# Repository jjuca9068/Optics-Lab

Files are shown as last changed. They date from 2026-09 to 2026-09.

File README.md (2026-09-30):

# Table of Contents
* [1. Lab Stage Mounts (3D CAD Design)](#1-optical-fiber-heating-enclosure-3d-cad-design)
* [2. Integrated Lab Control & Vision System GUI](#2-integrated-lab-control--vision-system-gui)
* [3. Hydrogen Flame Draft Protection Enclosure](#3-hydrogen-flame-draft-protection-enclosure)
* [4. Project Presentations & Documentation](#4-project-presentations--documentation)
---

# 1. Quantum Optics Lab Stage Mounts
Personal portfolio and technical projects for the MTSU Quantum Optics Lab, featuring custom CAD hardware, mechanical frame layouts, and an AI-assisted instrument control system.

### 1.1 Project Task & Engineering Challenge
* **Objective:** Securely mount specialized fiber holders onto translational stages to draw optical fiber under controlled tension over a hydrogen flame.
* **Constraints:** Commercial stage hardware lacked the proper clearance, vertical offset, and stability required for precise repeatable results.
* **Goal:** Design, iterate, and deploy a custom, high-rigidity stage mount to optimize precision and repeatability.

---

### 1.2 Design Logic & Prototyping Approach
* **Modular Two-Part System:** Split the mount into a **Base Plate** (interfaces directly with the stage) and a **Top Bracket** (clamps the fiber fixture) for fast alignment adjustments and component swapping.
* **Universal Dual-Hole Pattern:** Integrated symmetric mounting holes into the base plate design. This allows a single printed part to be deployed interchangeably on either the left or right side of the stage setup, eliminating the need to design and manage separate left- and right-handed models.
* **Prototyping Strategy:** Utilized 3D-printed PETG/PLA for rapid dimensional validation and clearance testing before final deployment.
* **Thermal Considerations:** Designed clearance offsets relative to the flame source to prevent localized heating or material sagging during active fiber drawing runs.

---

### 1.3 Iteration History & Development

#### Phase 1: Early Prototypes & Initial Fit Check
Initial spatial checks to test stage mounting hole spacing and overall base plate geometry.

| Base Plate (V1) | Stage Fit Check Assembly |
| :---: | :---: |
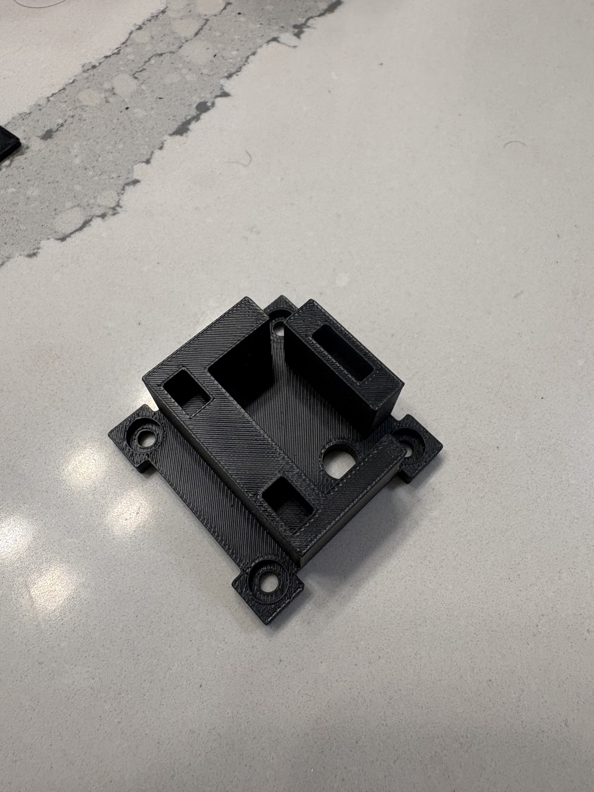
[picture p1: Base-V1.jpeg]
Base V1
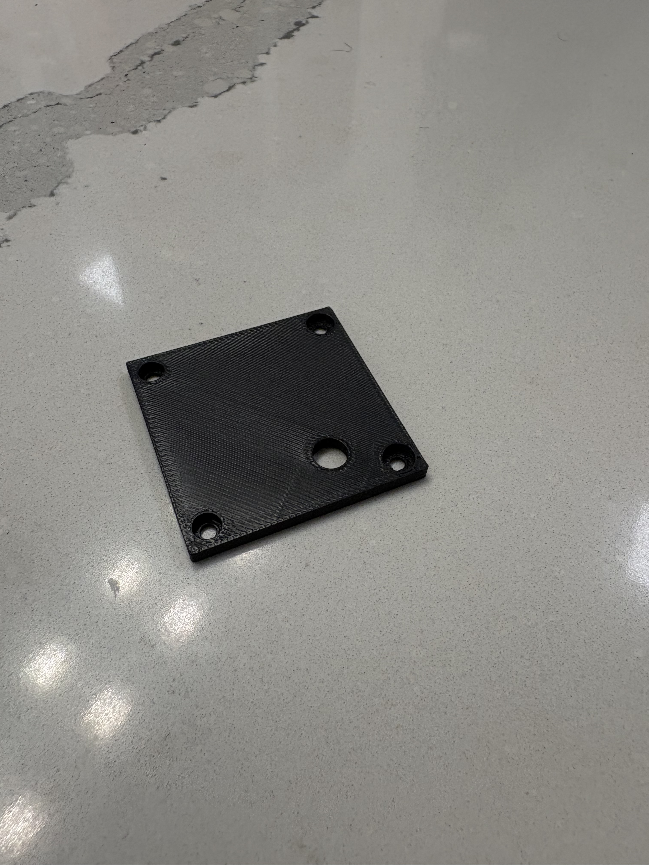
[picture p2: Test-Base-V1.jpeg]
Test Assembly
|  |  |
| *Initial base mounting plate* | *Assembled fit-check on stage* |

---

#### Phase 2: Top Bracket & Binding Clearance Analysis
Evaluating upper bracket geometry and identifying translation binding issues.

| Top Bracket (V1) | Failed Fit Check (Side View) |
| :---: | :---: |
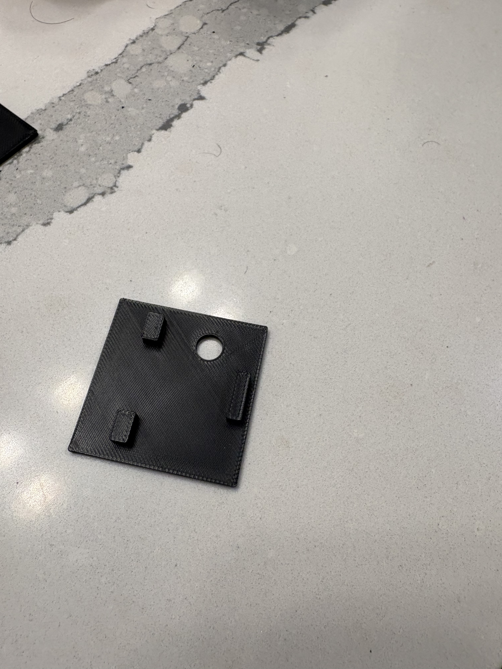
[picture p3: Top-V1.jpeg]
Top V1
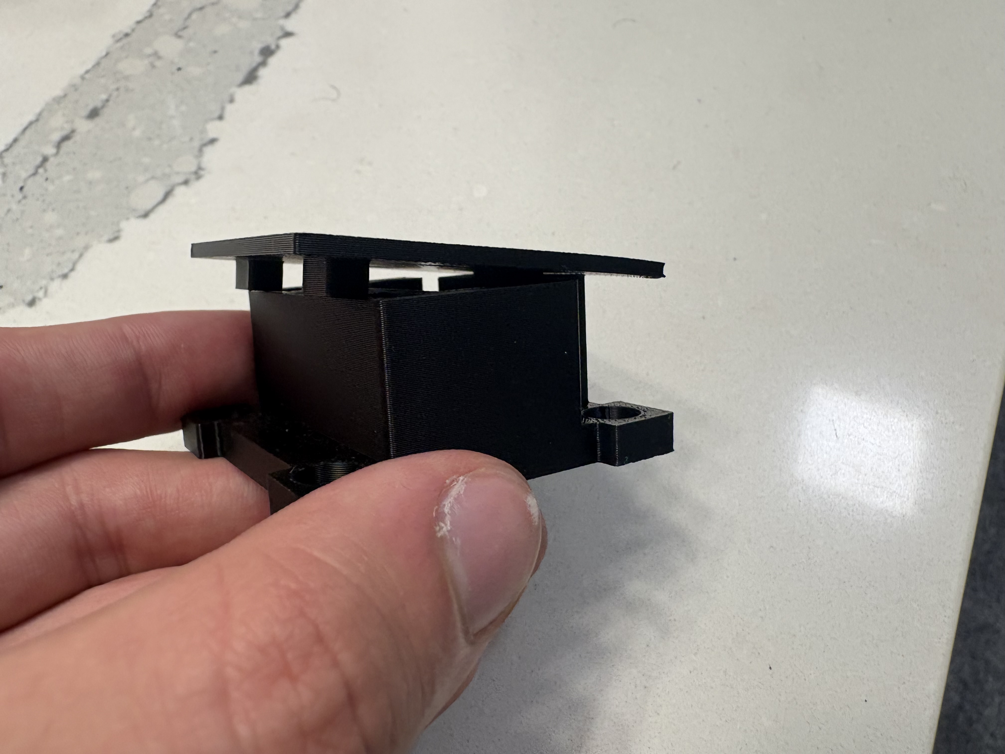
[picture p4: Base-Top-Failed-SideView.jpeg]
Failed Side View
|  |  |
| *First top bracket geometry* | *Side view clearance breakdown* |

* **Key Finding:** Initial V1 geometry did not line up. Adjustments were made to side offsets and hole counterbores for subsequent revisions.

---

#### Phase 3: Refined Base Plate Geometry & Alignment Fit
Upgraded base plate design featuring reinforced side walls, corrected stage hole tolerances, and physical fit verification.

| Base Plate (V2) | Alignment Verification |
| :---: | :---: |
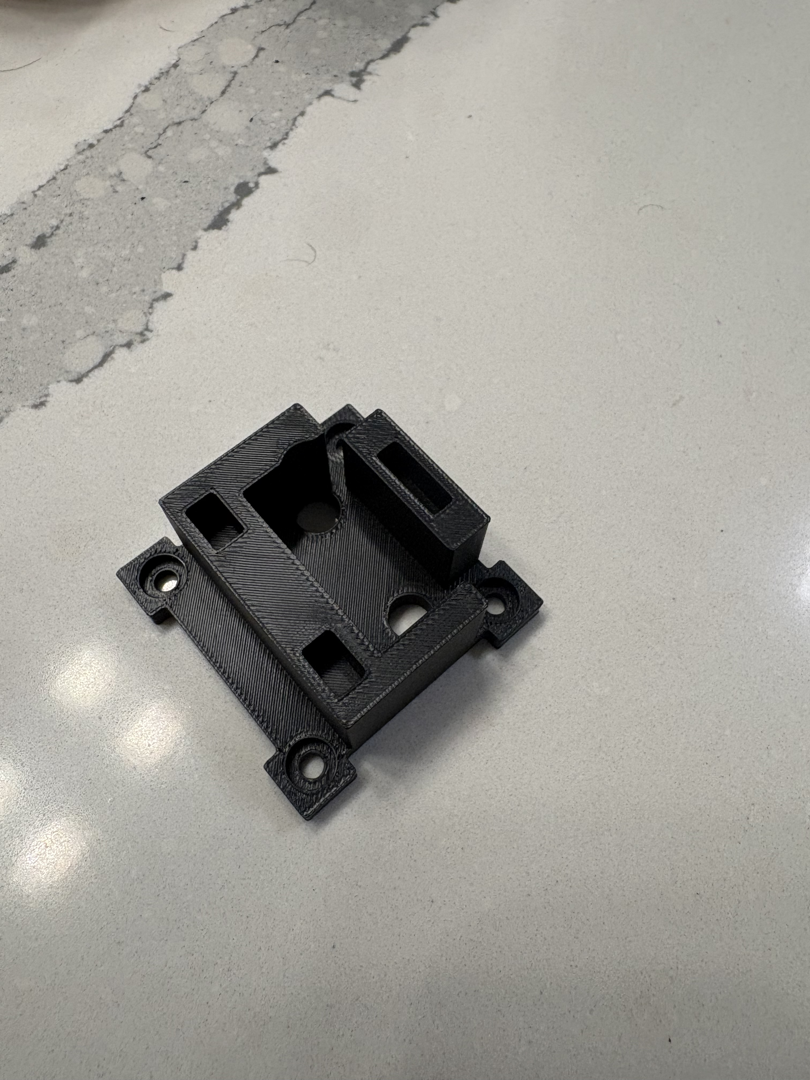
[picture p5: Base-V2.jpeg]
Base V2
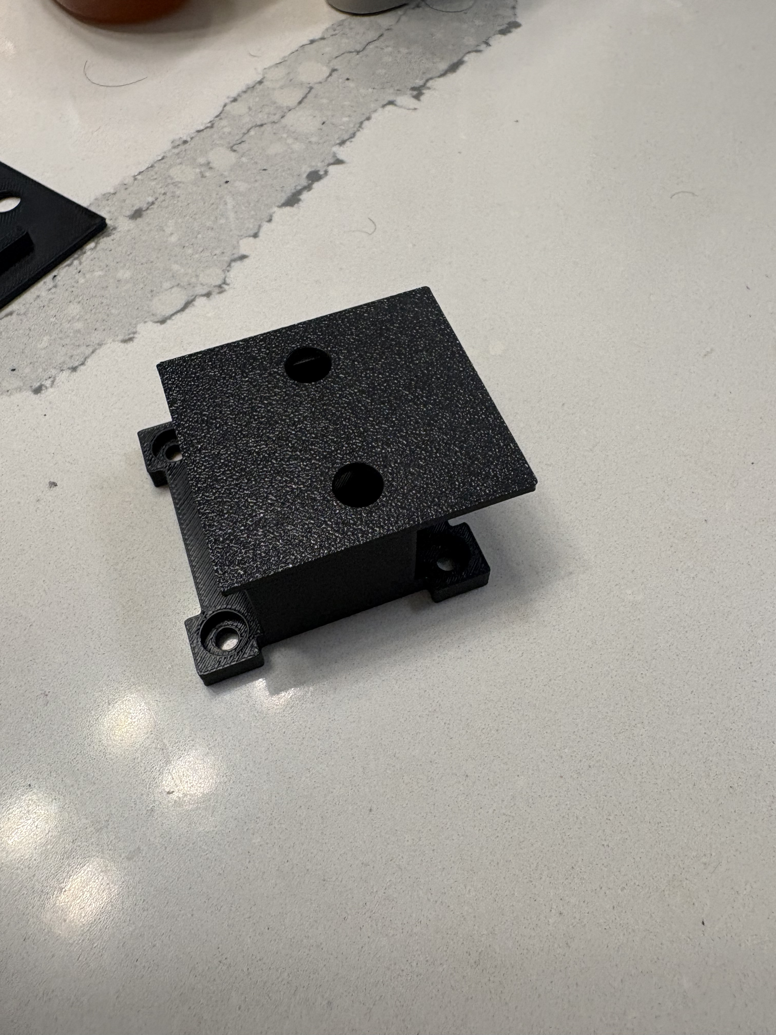
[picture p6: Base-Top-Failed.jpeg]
Failed Alignment
|  |  |
| *Reinforced base plate V2* | *Alignment verification and clearance test* |

---

#### Phase 4: Final Production Setup
Final assembly integrated and active in the laboratory fiber tapering rig.

| Final Deployment | Overhead View | Mount Interface Detail |
| :---: | :---: | :---: |
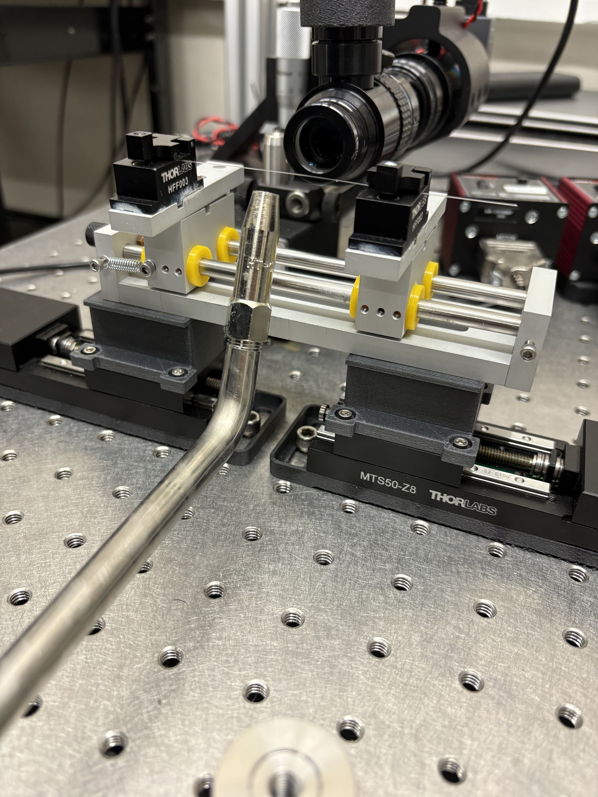
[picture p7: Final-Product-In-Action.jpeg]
Final Assembly
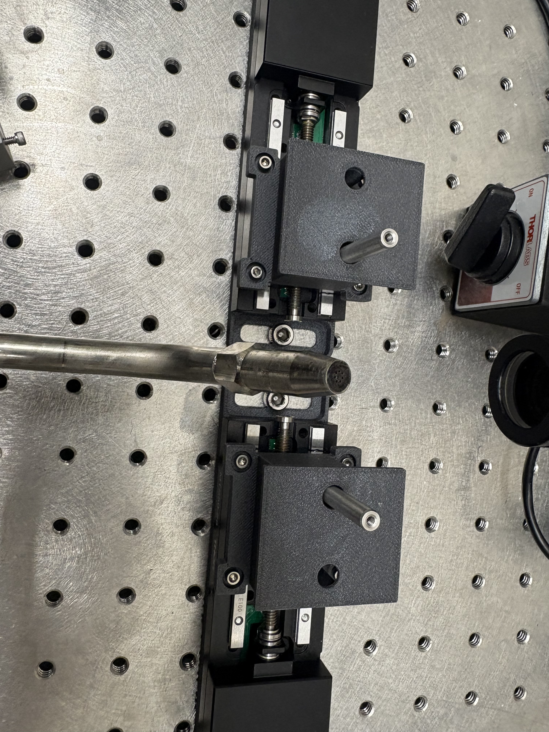
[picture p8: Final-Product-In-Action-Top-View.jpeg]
Top View
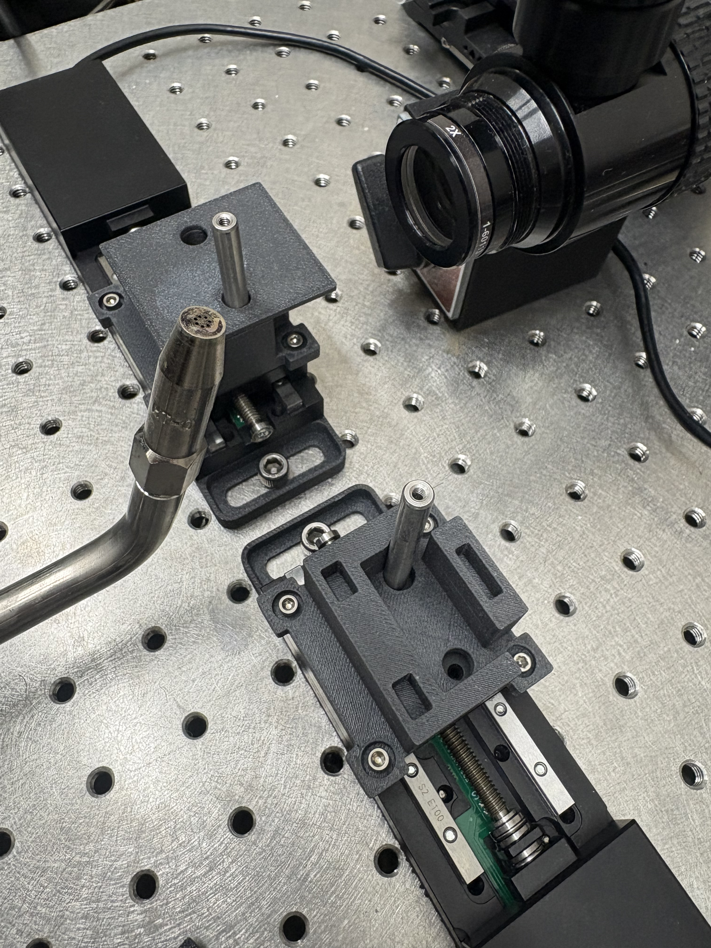
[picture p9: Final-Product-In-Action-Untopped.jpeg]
Untopped
|  |  |  |
| *In operation over hydrogen flame* | *Overhead optical alignment check* | *Stage mounting interface* |

---

### 1.4 3D Printable Models (STL)

Click any link below to view or rotate the 3D models directly on GitHub:

* **[Final Design](Final_Design.stl)**
* **[Full Base V2](Full_Base_V2.stl)**
* **[Top V2](Top_V2.stl)**
* **[Top V1](Top_V1.stl)**
* **[Full Base V1](Full_Base_V1.stl)**
* **[Base V1](Base_v1.stl)**
* **[Prototype 2](Prototype_number_2.stl)**
* **[Prototype 1](Prototype_number_1.stl)**

---

### 1.5 Summary & Key Results
* **Alignment & Versatility:** Successfully eliminated stage binding with a dual-hole universal base plate that mounts on either side of the setup.
* **Rigidity:** Modular clamp system holds fiber under tension without mechanical drift.
* **Cost & Time:** Iterated through spatial fit checks via 3D printing in hours, bypassing expensive trial-and-error machining.

### 2.1 Hardware Architecture & System Goals

* **Primary Objective:** Unify separate hardware peripherals (motor controllers and high-resolution camera feed) into one cohesive, browser-accessible dashboard.
* **Core Functionality:** Enable real-time motor stage translation, synchronized sequence routines, live video feed observation, image capture, and calibrated spatial measurements in micrometers ($\mu\text{m}$).

| System Goals | Integrated Hardware Peripherals |
| :--- | :--- |
| • **Simplified Motor Control:** Centralized axis position monitoring, homing, and safety stops. | • **2x Thorlabs Motor Controllers** (KDC101 Servo Controllers) |
| • **Unified Interface:** Integrated live camera streaming alongside dual-axis translation controls. | • **2x Thorlabs Translation Stages** |
| • **Preset Camera Control:** Adjustable exposure, gain, auto-scaling, and resolution controls. | • **1x Pixelink Industrial Camera** |
| • **In-Situ Measurement:** Direct pixel-to-micrometer dimensional measurement overlay. | • **1x Optical Microscope Assembly** |

---

### 2.2 System Architecture & Logic Map

The application follows a full-stack architecture with an asynchronous HTTP API layer linking the client dashboard to hardware-driver Python scripts.

| System Logic & Software Flow |
| :---: |
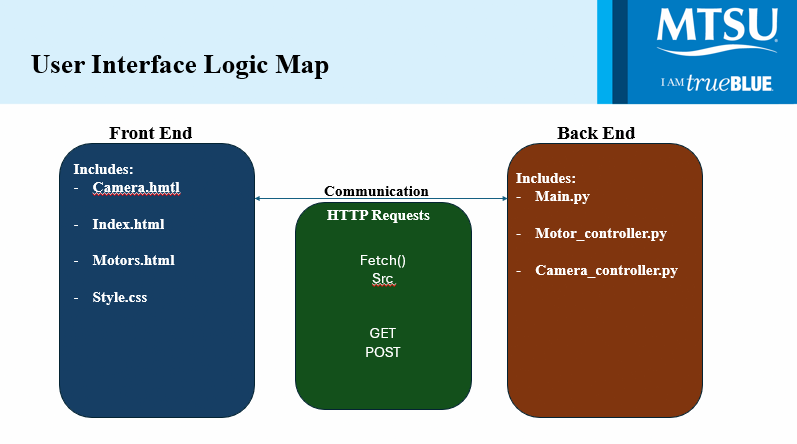
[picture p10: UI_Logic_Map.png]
User Interface Logic Map
|  |
| *Frontend-to-backend communication architecture via HTTP GET/POST requests* |

#### Technical Stack Breakdown:
* **Front End:** HTML5, CSS3, JavaScript (Fetch API for asynchronous `GET`/`POST` requests, responsive canvas overlays for measurement calculations).
* **Back End:** Python (RESTful API hosting via `main.py`), controlling physical devices through submodules (`motor_controller.py` and `camera_controller.py`).
* **Communication Protocols:** JSON payload response handling for real-time motor telemetry (positioning, idle status) and live video streaming.

---

### 2.3 System Layout & Hardware Deployment

The entire system runs on a dedicated laboratory laptop, providing direct USB interface lines to all optomechanical components mounted on the optical table.

| Presentation View | Physical Laboratory Setup |
| :---: | :---: |
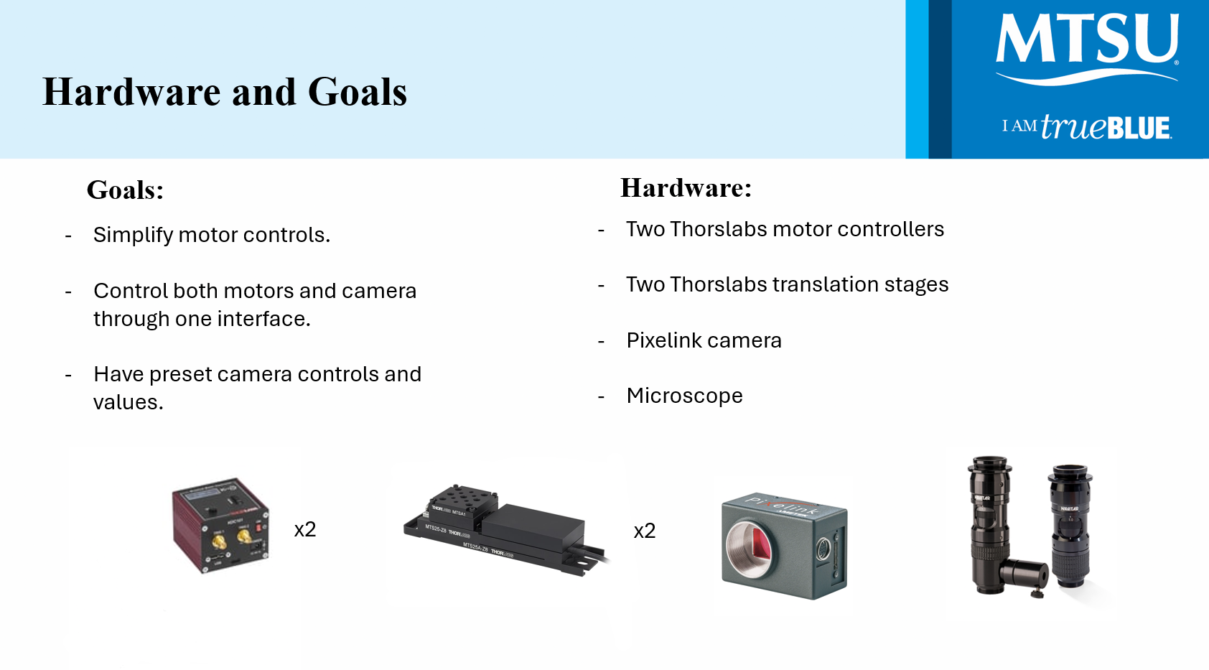
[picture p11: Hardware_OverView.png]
Hardware Overview
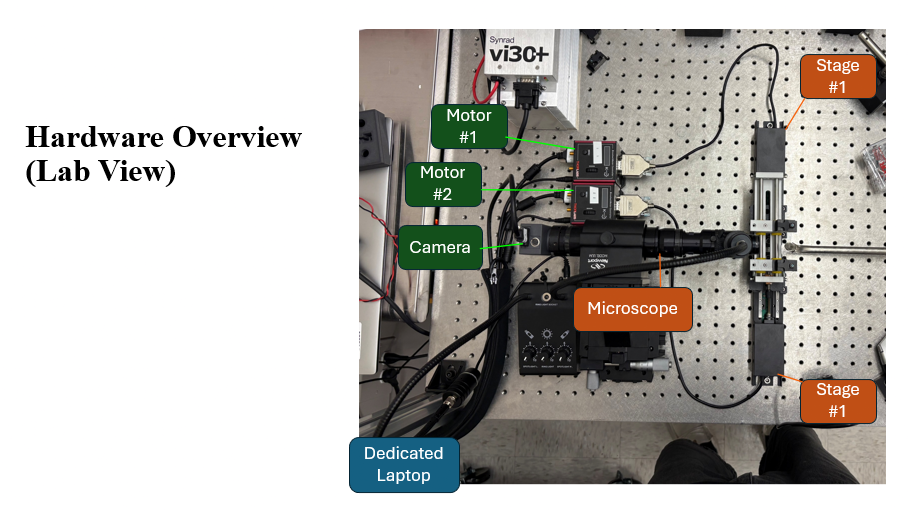
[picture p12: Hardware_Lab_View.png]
Lab Hardware Setup
|  |  |

---

### 2.4 User Interface & Operational Control

#### 1. Main Control Dashboard (`index.html`)
Consolidates motor operations and vision streaming into a single view for active experimentation.

| Dashboard Overview | Key Dashboard Features |
| :---: | :--- |
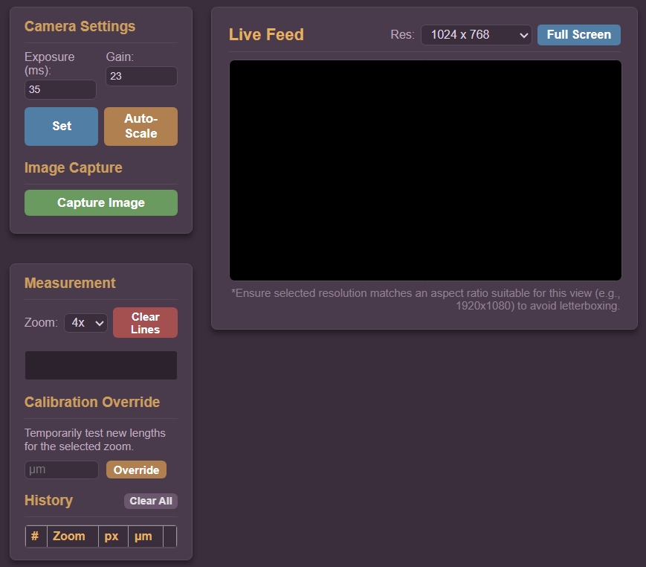
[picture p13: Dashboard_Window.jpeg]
Main Dashboard
|  | • **Dual Motor Monitoring:** Live position readout ($mm$) and status tracking (Idle / Active).<br>• **Independent Axis Actions:** Homing, pausing, resuming, and stopping per motor.<br>• **Global Safety Controls:** One-click `Pause Both`, `Resume Both`, and emergency `Stop Both`.<br>• **Automated Sequences:** Dropdown selector to execute synchronized movement routines.<br>• **Quick Capture:** Instant single-frame optical capture directly from the main view. |

---

#### 2. Detailed Motor Control View (`motors.html`)
Dedicated view for granular dual-axis stage configuration, step control, and sequence selection.

| Motor Control Interface | Key Capabilities |
| :---: | :--- |
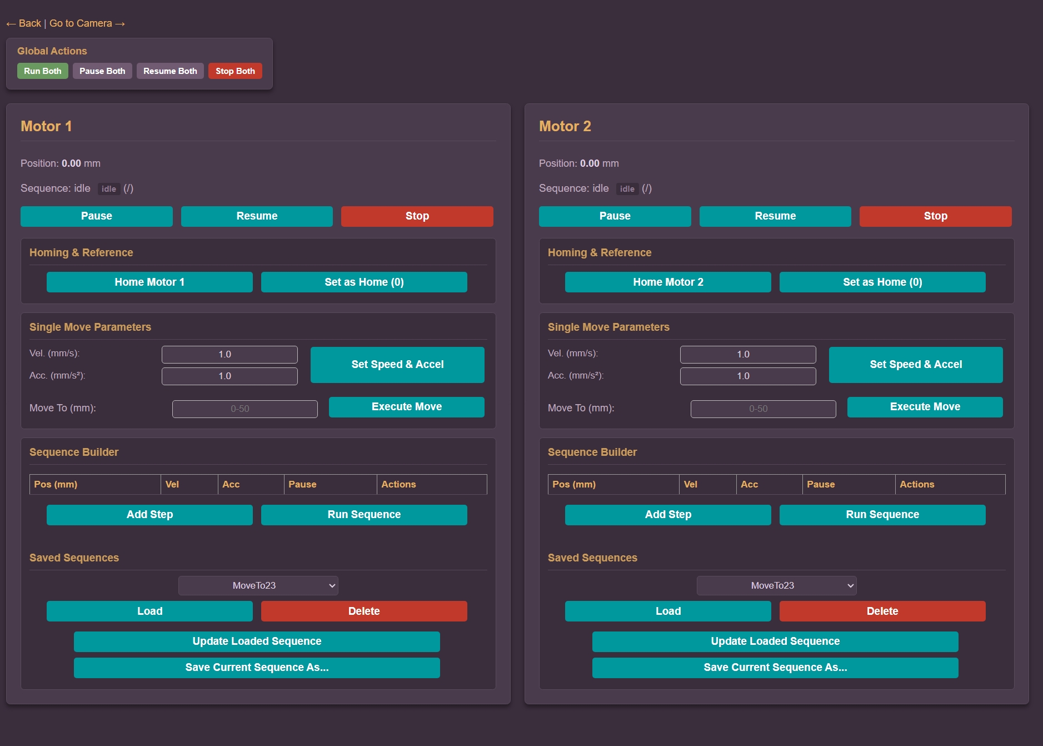
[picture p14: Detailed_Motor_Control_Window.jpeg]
Detailed Motor Control
|  | • **Axis Specific Readouts:** Individual telemetry windows for Stage 1 and Stage 2.<br>• **Manual & Step Moves:** Direct step-size configuration for precision alignment.<br>• **Independent Axis Safety:** Individual Home, Pause, Resume, and Stop toggles per motor driver.<br>• **Routine Automation:** Direct access to automated drawing and translation scripts. |

---

#### 3. Specialized Camera & Dimensional Measurement View (`camera.html`)
Dedicated view for fine alignment, sensor parameter tuning, and in-situ micro-scale measurement.

| Camera & Measurement Suite | Features & Capabilities |
| :---: | :--- |
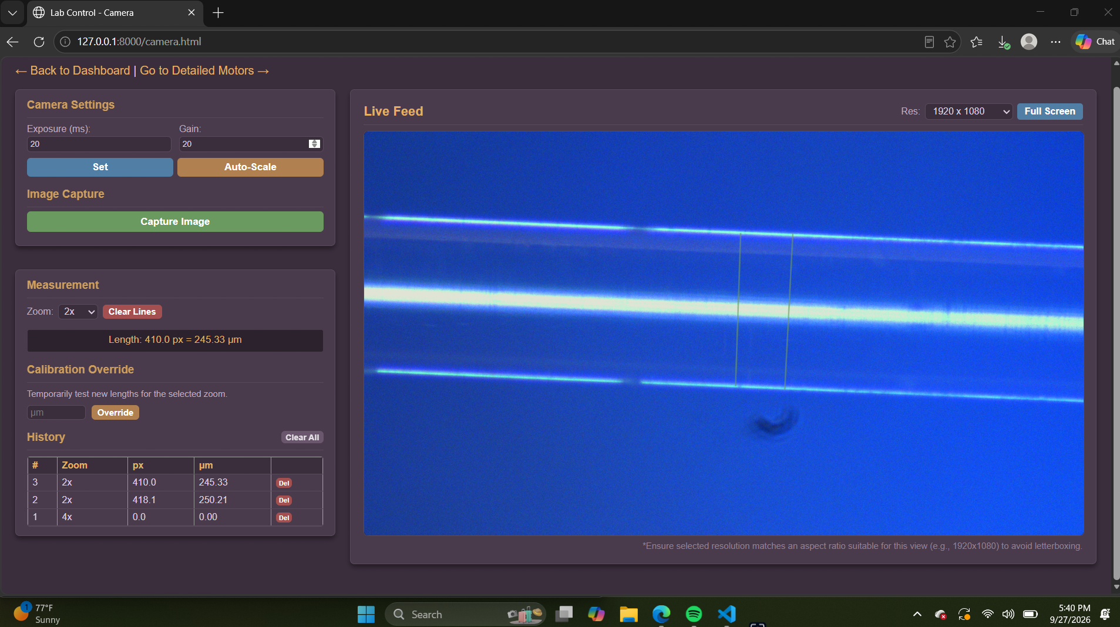
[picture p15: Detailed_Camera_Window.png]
Camera Controls
|  | • **Camera Parameter Tuning:** Manual entry for Exposure ($ms$) and Gain, alongside one-click Auto-Scale.<br>• **Resolution Control:** Selectable aspect ratios up to $5472 \times 3648$.<br>• **Micrometer Calibration Overlay:** Interactive line-drawing tool converts pixel distance ($px$) directly to micro-scale length ($\mu\text{m}$) based on selected microscope zoom magnification ($1\text{x}, 2\text{x}, 4\text{x}$).<br>• **Measurement Log & Calibration Override:** Real-time history table keeping track of measured fiber dimensions with quick deletion and manual calibration test overrides. |

---

### 2.5 Software Repository & Source Files

Click any file below to view the source code directly in this repository:

#### **Back End (Python Server & Controllers)**
* 🐍 **[main.py](./main.py)** – Server entry point, API route management (`GET`/`POST`), and initialization routines.
* 🐍 **[motor_controller.py](./motor_controller.py)** – Driver interface translating API commands into Thorlabs motor translation movement.
* 🐍 **[camera_controller.py](./camera_controller.py)** – Pixelink camera SDK wrapper for frame capture, exposure adjustments, and video feed serving.

#### **Front End (User Interface)**
* 📄 **[index.html](./index.html)** – Main laboratory dashboard layout.
* 📄 **[camera.html](./camera.html)** – Dedicated live video feed, camera settings, and line-measurement interface.
* 📄 **[motors.html](./motors.html)** – Detailed standalone motor stage configuration page.
* 🎨 **[style.css](./style.css)** – UI styling, dark mode theme, and responsive panel layouts.

---

### 2.6 Summary & Key Accomplishments

* **Integrated Workflow:** Replaced separate, single-purpose vendor software utilities with a lightweight, browser-based control hub.
* **In-Situ Metrology:** Added pixel-calibrated measurement overlays, allowing researchers to measure fiber tapers directly inside the live camera feed without exporting images to external software.
* **Synchronized Automation:** Enabled multi-axis automated movement sequences managed through backend Python routines for repeatable fiber-drawing procedures.

# 3. Hydrogen Flame Draft Protection Enclosure

An environmental isolation frame engineered for the MTSU Quantum Optics Lab to shield sensitive hydrogen micro-flames from ambient laboratory air currents during optical fiber tapering operations.

---

### 3.1 Problem Statement & Solution Overview

* **Problem:** Ambient HVAC airflow and air currents inside the laboratory caused temperature fluctuations and instability in the hydrogen micro-flame, leading to uneven optical fiber tapers.
* **Solution:** Built a rigid 4040 aluminum extrusion frame utilizing heavy-duty corner bracket connectors, sliding T-slot hooks, and flame-retardant protective curtains to isolate the flame zone without interfering with optomechanical stage access.

| Project Focus | Structural Features |
| :--- | :--- |
| • **Flame Stabilization:** Eliminates micro-drafts around the hydrogen burner nozzle. | • **Heavy-Duty Framing:** Industrial-grade 4040 aluminum extrusion rails. |
| • **Unrestricted Lab Access:** Smooth sliding curtain suspension along extrusion slots. | • **Modular Assembly:** Secured via M8 T-slot nuts and corner profile connectors. |

---

### 3.2 Structural Frame, Layout & Assembly Views

| Initial Concept Sketch | Assembled Frame (Top View) | Corner Connector Detail |
| :---: | :---: | :---: |
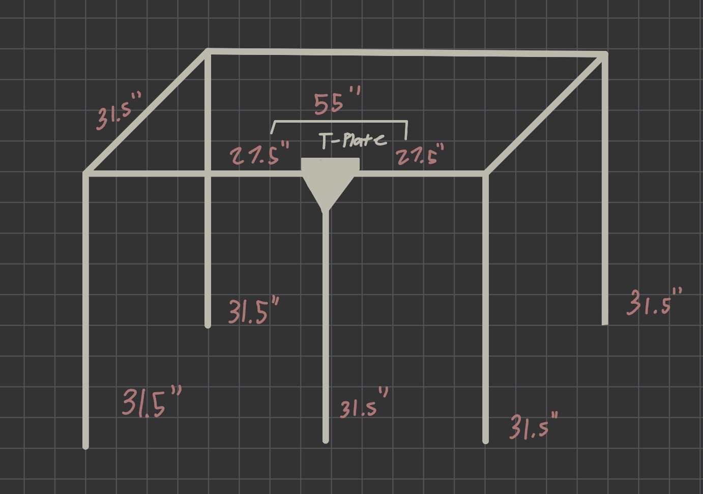
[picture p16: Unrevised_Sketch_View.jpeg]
Initial Concept Sketch
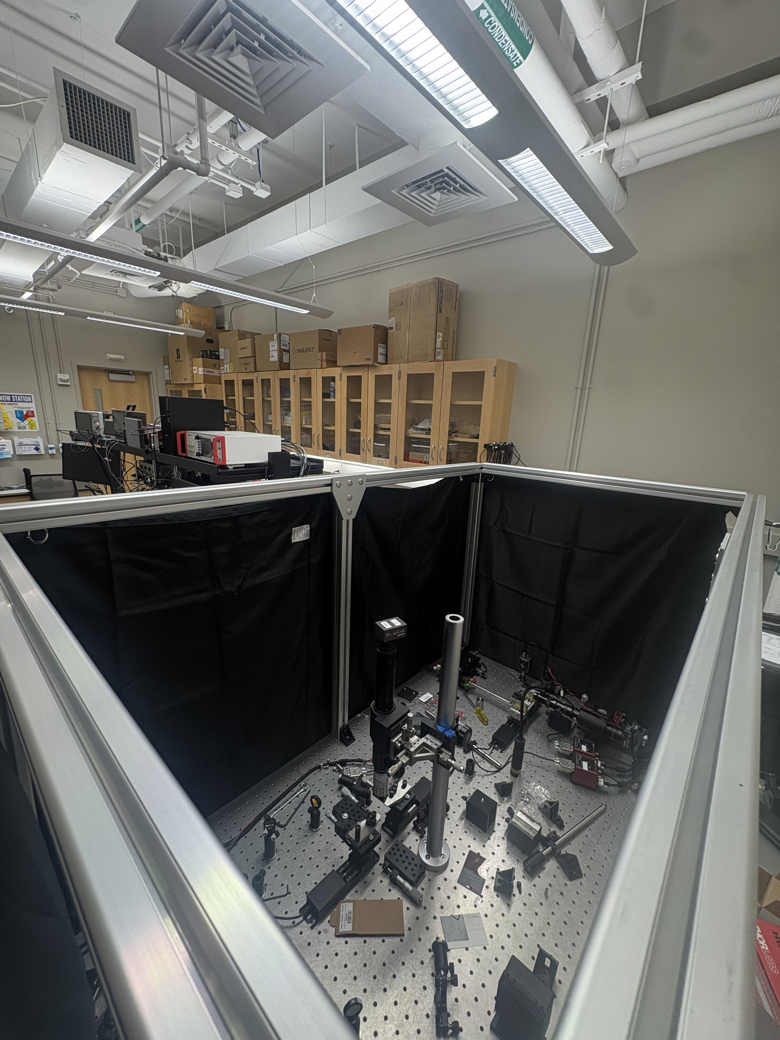
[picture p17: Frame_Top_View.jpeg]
Frame Top View
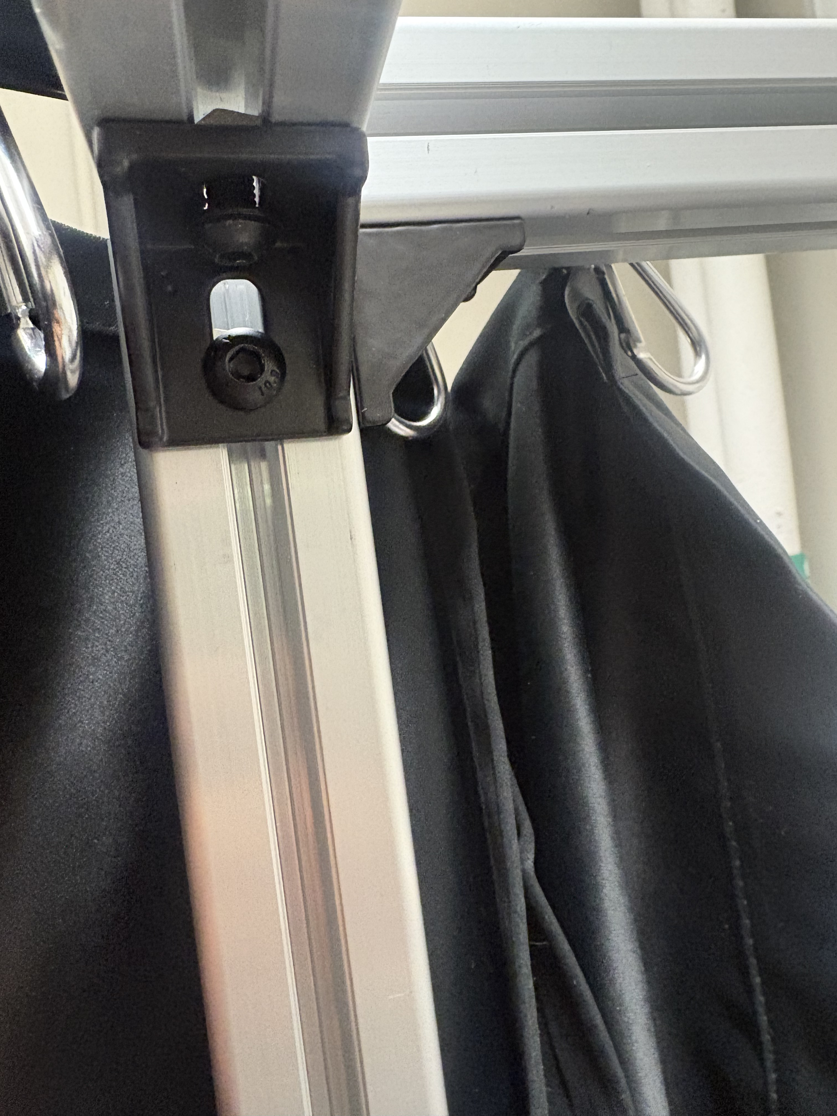
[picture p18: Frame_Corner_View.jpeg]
Corner Joint Detail
|  |  |  |
| *Initial structural layout and dimensioning sketch* | *Top-down perspective of assembled aluminum frame* | *Close-up of 4040 aluminum corner brackets holding frame rails* |

#### Bill of Materials & Hardware Specifications

| Component / Hardware Item | Quantity | Material / Description | Function |
| :--- | :---: | :--- | :--- |
| **4040 Aluminum Extrusion Rails (800mm)** | 6 Rails | Silver Anodized Linear Rail ($800\text{mm}$) | Primary vertical and upper structural framing rails |
| **4040 Aluminum Extrusion Rails (700mm)** | 6 Rails | European Standard Silver Rail ($700\text{mm}$ / 27.5") | Base and cross-member support framing rails |
| **3540 Corner Bracket Connectors** | 14 Units | Black Anodized Corner Profile Connectors | Rigid $90^\circ$ right-angle joint connectors securing rails |
| **Extrusion Sliding Hooks** | 12 Pack | Black 3030/4040 Extrusion T-Slot Hooks | Slide-in rail hooks supporting protective curtains |
| **T-Slot Fasteners & Hex Bolts** | 1 Set | M8 T-Slot Sliding Nuts & Hex Screws | Hardware locking corner brackets into rail grooves |
| **Draft Protection Curtains** | 4 Panels | Flame-Retardant Anti-Draft Vinyl | Hanging barrier blocking ambient HVAC air currents |

---

### 3.3 Summary & Impact

* **Enhanced Flame Stability:** Successfully isolated the hydrogen flame zone from ambient lab drafts, stabilizing thermal delivery during fiber heating.
* **Repeatable Fiber Tapering:** Reduced geometrical variations in drawn optical fibers caused by flicker or flame drift.
* **Modular Construction:** Designed with industrial T-slot profiles allowing quick repositioning or height adjustments on the optical bench.

* ---

# 4. Project Presentations & Slide Decks

Detailed PowerPoint slide presentations covering system design, laboratory architecture, and research methodology for the project components.

| Presentation Slide Deck | File Format | Description & Topic Focus | Direct Link |
| :--- | :---: | :--- | :---: |
| **Web GUI & Instrument Control** | `.pptx` | Overview of the web-based instrument control system, motor stage API, and live camera measurement suite. | 📊 **[`web-GUI-presentation.pptx`](./web-GUI-presentation.pptx)** |
| **Tapered Optical Fiber & WGM** | `.pptx` | Slide deck detailing Tapered Optical Fiber (TOF) fabrication and Whispering Gallery Mode (WGM) optical resonance research. | 📊 **[`TOFxWGM presentation.pptx`](./TOFxWGM%20presentation.pptx)** |

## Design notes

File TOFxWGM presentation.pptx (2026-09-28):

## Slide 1

Tapered Optical Fiber and Whispering-Gallery Mode Resonators

High-Sensitivity Optical Sensing

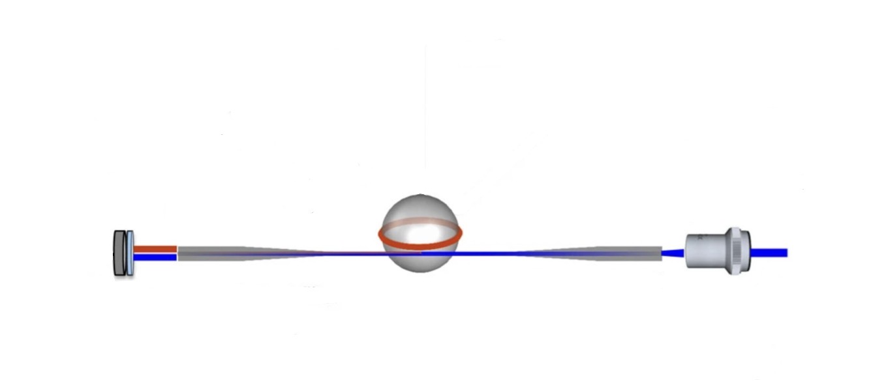
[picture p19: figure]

Jacob Juca
MTSU Quantum-Optics
07/31/26

Grivas et al., Single-mode tunable laser emission in the single-exciton regime from colloidal nanocrystals (2013).

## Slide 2

Why High-Sensitivity Optical Sensors?

Zhang et al., Advances in Tapered Optical Fiber Sensor Structures: From Conventional to Novel and Emerging (2021).

- Detect extremely small changes in physical and chemical environments.
- Increase the interaction between light and surrounding materials.
- Convert small environmental changes into measurable optical signals.

2

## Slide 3

Optical Sensor System Overview

Input

Optical Fiber

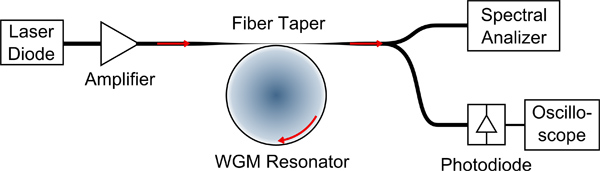
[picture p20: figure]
Sound source localization by Ormia ochracea inspired low–noise ...

Optical Analyzer

Whispering-Gallery Mode Resonator

Coillet et al., Microwave Photonics Systems Based on Whispering-Gallery-Mode Resonators (2013).

3

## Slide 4

Optical Sensor System Overview Explained

Tunable Laser Source: Provides controlled optical input

Tapered Fiber: Couples light into the resonator

Input

Optical Fiber

Analyzer

WGM Resonator

Coillet et al., Microwave Photonics Systems Based on Whispering-Gallery-Mode Resonators (2013).

Resonator: Traps light (evanescent field) in a repeating circular path

Optical Spectrum Analyzer: Measures wavelength shifts

4

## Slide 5

Light Confinement in Optical Fibers

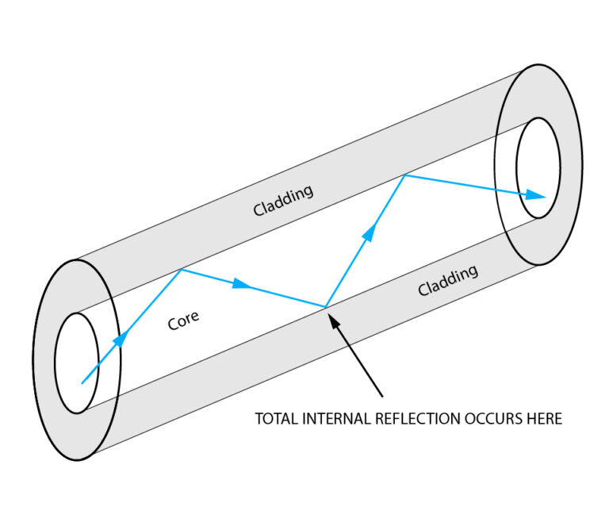
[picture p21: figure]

LSO Link, Everything You Need to Know About Single Mode Fiber Optic Cable (2025).

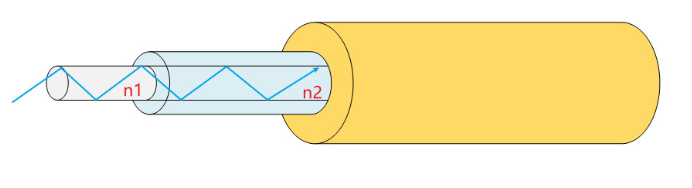
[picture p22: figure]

Eagle Group, How Does a Fiber Laser Work? (2022).

Core

Cladding

Outer Layer

Snell’s Law:

Because:

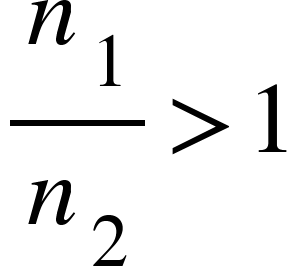
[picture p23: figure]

Becomes:

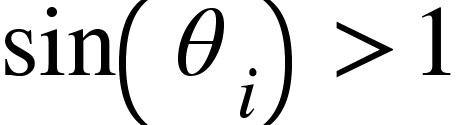
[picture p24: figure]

Total Internal Reflection!

5

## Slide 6

Tapered Optical Fibers and Sensing

Evanescent Field:
A decaying electromagnetic field that extends beyond the fiber core and enables light–matter interaction

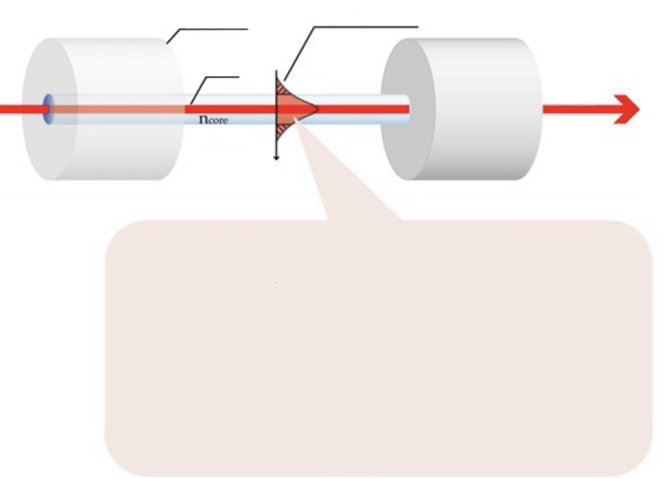
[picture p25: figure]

Cladding

Core

Evanescent Field

Soares et al., Immunosensing Based on Optical Fiber Technology: Recent Advances, (2021)

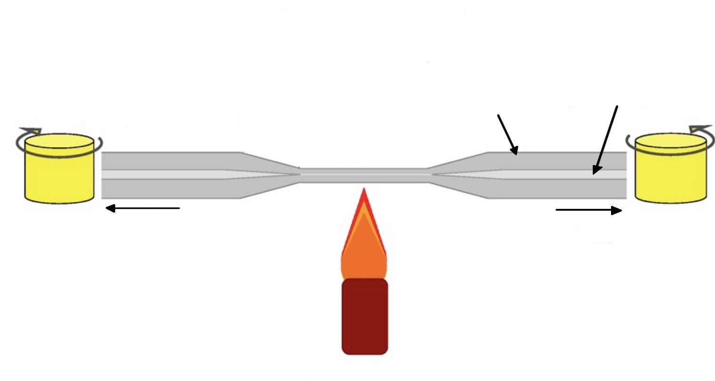
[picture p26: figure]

Rotating stage

Cladding

Core

Rotating stage

Heat

Yu et al., Fabrication of an Optical Fiber Micro-Sphere with a Diameter of Several Tens of Micrometers,(2014)

6

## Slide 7

Whispering-Gallery Mode (WGM) Resonators

Zheng et al., Sensing and Lasing Applications of Whispering Gallery Mode Microresonators, 2018)

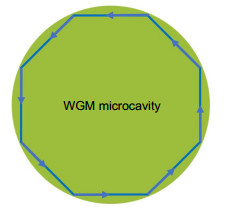
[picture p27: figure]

Resonance occurs when the optical path length equals an integer multiple of the wavelength.

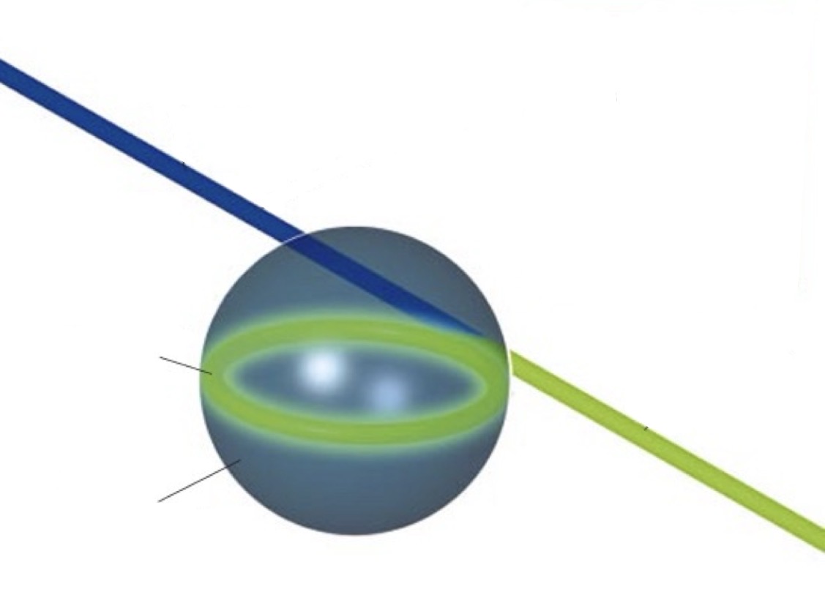
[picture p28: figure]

Vahala, Optical Microcavities, (2003)

= m mode

Silica Microsphere

Quality Factor: Q

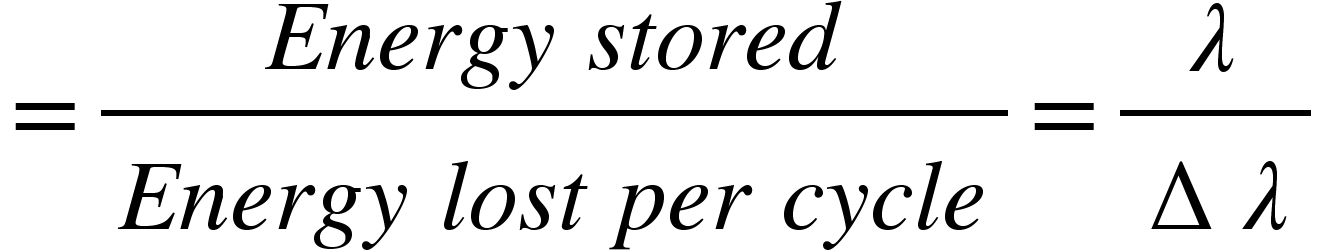
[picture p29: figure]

7

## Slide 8

Complete WGM Optical Sensing System

1) Laser excites the tapered fiber

2) Evanescent coupling transfers light into the WGM resonator.

3) Environmental changes shift the resonance.

4) The optical spectrum analyzer and power meter detect the resulting signal.

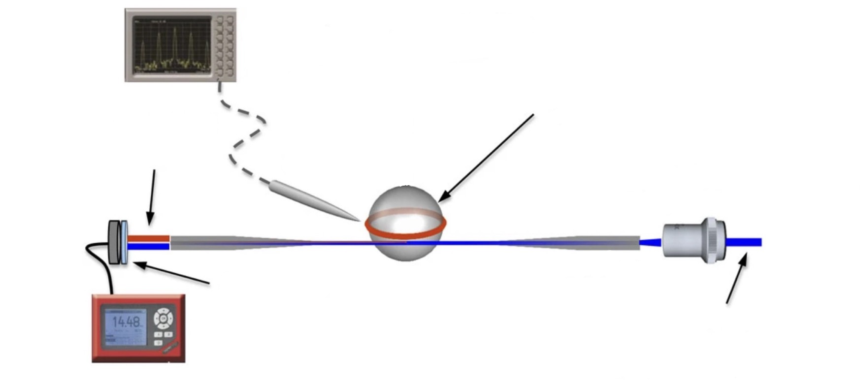
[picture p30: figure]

Spectrum Analyzer

Silica Microsphere

Power Meter

Tunable Laser

4

3

2

1

Grivas et al., Single-mode tunable laser emission in the single-exciton regime from colloidal nanocrystals (2013).

8

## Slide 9

Thank you for your attention!

I am open to any and all feedback!
Jacob Juca
jj8e@mtmail.mtsu.edu

9

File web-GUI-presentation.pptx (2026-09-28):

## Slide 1

Web Based Motor and Camera Controller

System Overview

Jacob Juca

MTSU Quantum Optics Lab
09/02/26

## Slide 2

Hardware and Goals

Hardware:

- Two Thorslabs motor controllers
- Two Thorslabs translation stages
- Pixelink camera
- Microscope

Goals:

- Simplify motor controls.
- Control both motors and camera through one interface.
- Have preset camera controls and values.

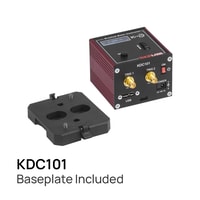
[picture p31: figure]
K-Cube<sup>®</sup> Brushed DC Servo Motor Controller

x2

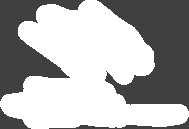
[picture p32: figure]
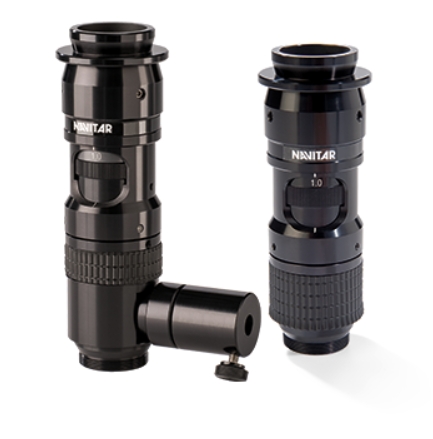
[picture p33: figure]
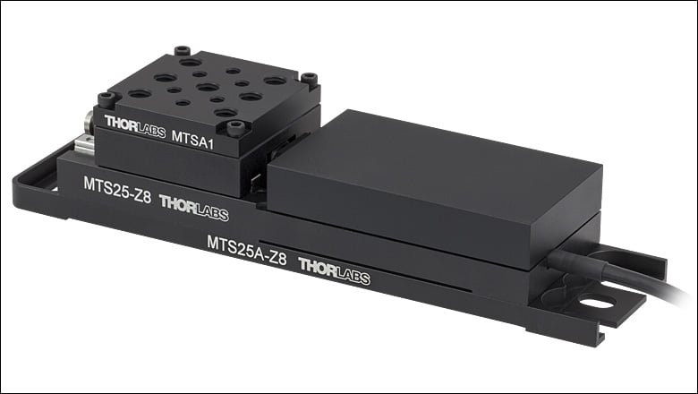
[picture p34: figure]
Thorlabs · 25 mm (0.98") Compact Motorized Translation Stage

x2

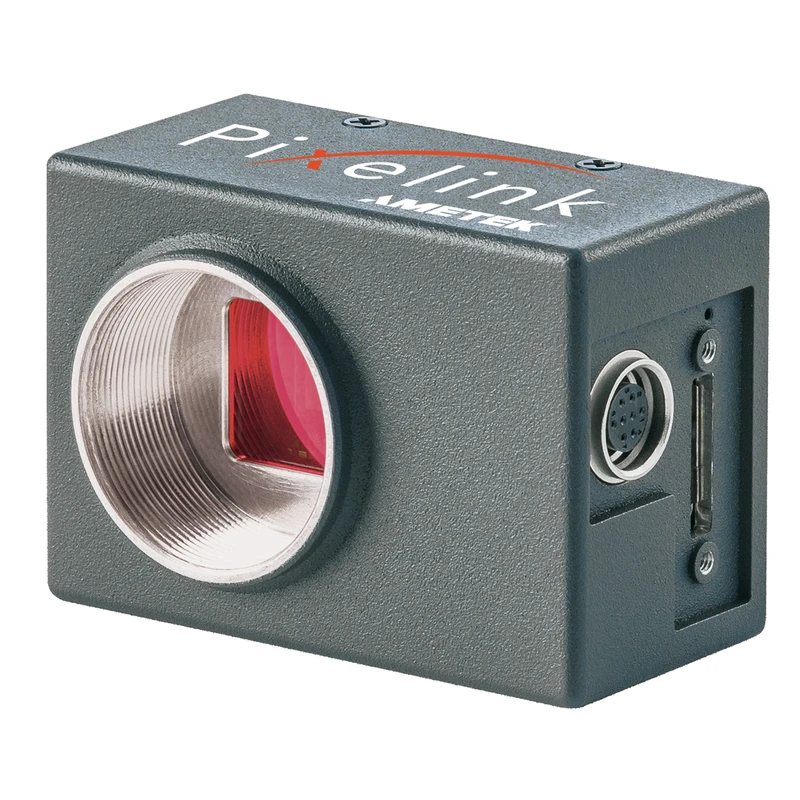
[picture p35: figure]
Pixelink Cameras - Machine Vision Cameras - AMETEK Navitar

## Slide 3

Hardware Overview

Dedicated Laptop

Motor #1

Motor #2

Stage #1

Stage #2

Camera

Microscope

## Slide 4

Hardware Overview (Lab View)

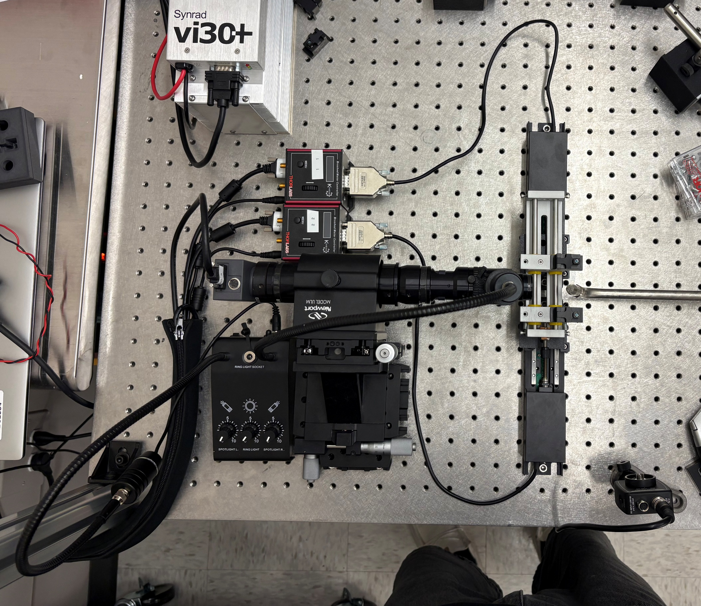
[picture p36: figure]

Stage #1

Microscope

Stage #1

Motor #1

Motor #2

Camera

Dedicated Laptop

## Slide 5

User Interface Logic Map

Front End

Includes:
- Camera.hmtl
- Index.html
- Motors.html
- Style.css

Back End

Includes:
- Main.py
- Motor_controller.py
- Camera_controller.py

Communication

Fetch()
Src
GET
POST

HTTP Requests

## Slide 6

Front End

Front End

- User Inputs: (buttons, text boxes, etc.)
- Network Communication: Uses requests to package user actions and send to the backend
- Visual Feedback: Receives JSON responses and live video frames

Index.html

Style.css

Motors.html

Camera.html

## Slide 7

Front End
(index.html)

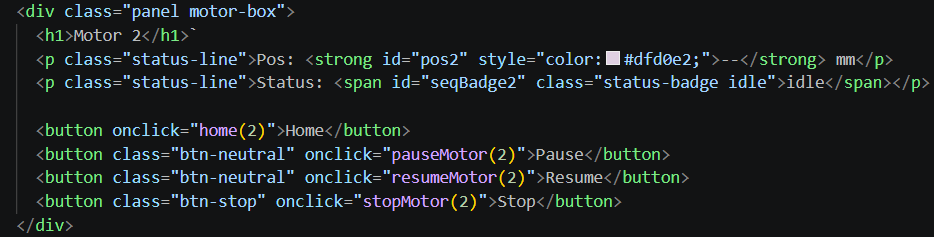
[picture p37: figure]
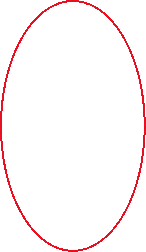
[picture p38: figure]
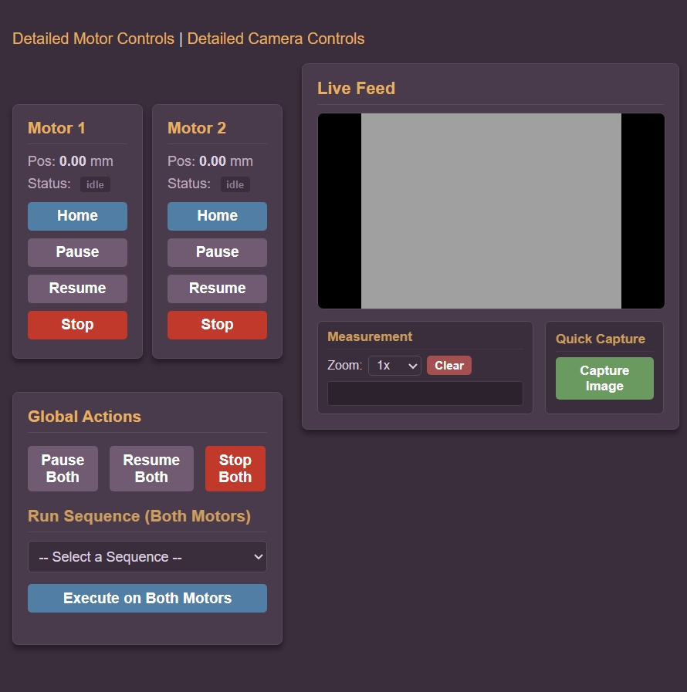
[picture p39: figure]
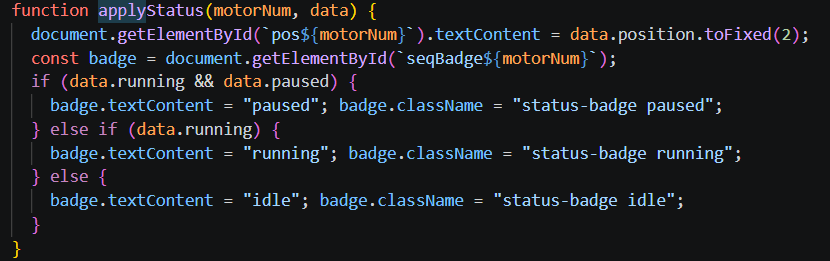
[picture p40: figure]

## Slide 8

Detailed Motor Control Page (motors.html)

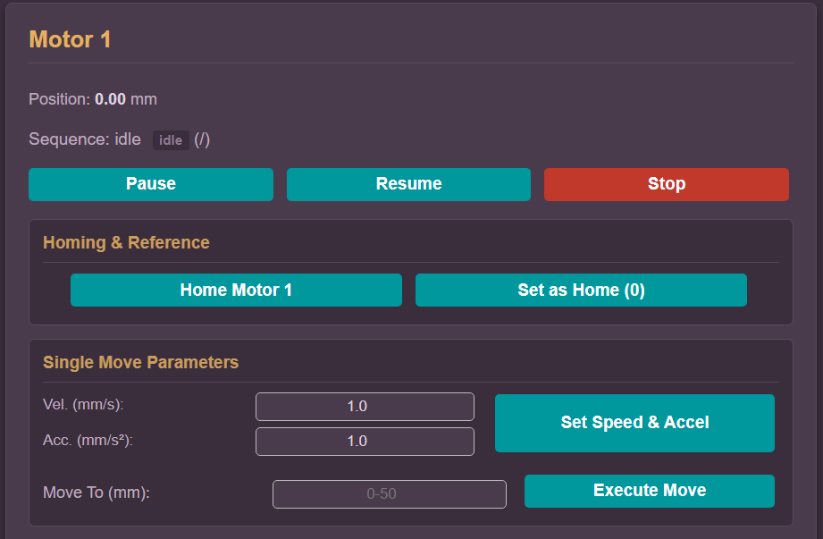
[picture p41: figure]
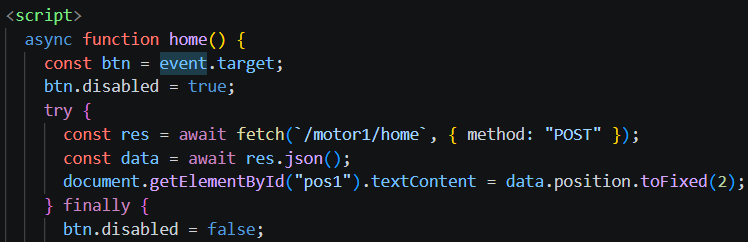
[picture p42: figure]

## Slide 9

Detailed Camera Control Page (camera.html)


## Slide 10

Back End

Back End

Main.py

Initializes server: Launches the web program and holds functions.
Hardware Control: Translates API commands into routines and configurations.
Manages Endpoints: Hosts API routes(GET,POST…) that act destinations for front end commands.

Motor_controller.py

Camera_controller.py

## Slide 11

Back End (main.py)

Initializes Server:


Declares Functions:

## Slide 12

Back End (motor_controller.py)

Import driver:
(library to interface with motors)


Communicate to hardware:

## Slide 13

Back End (camera_controller.py)


SDK:

Retrieve image from camera

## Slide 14

Front End to Back End

Front End

Button

Request Video Feed

Back End

Function

Video Feed

Fetch()

POST

GET

SRC

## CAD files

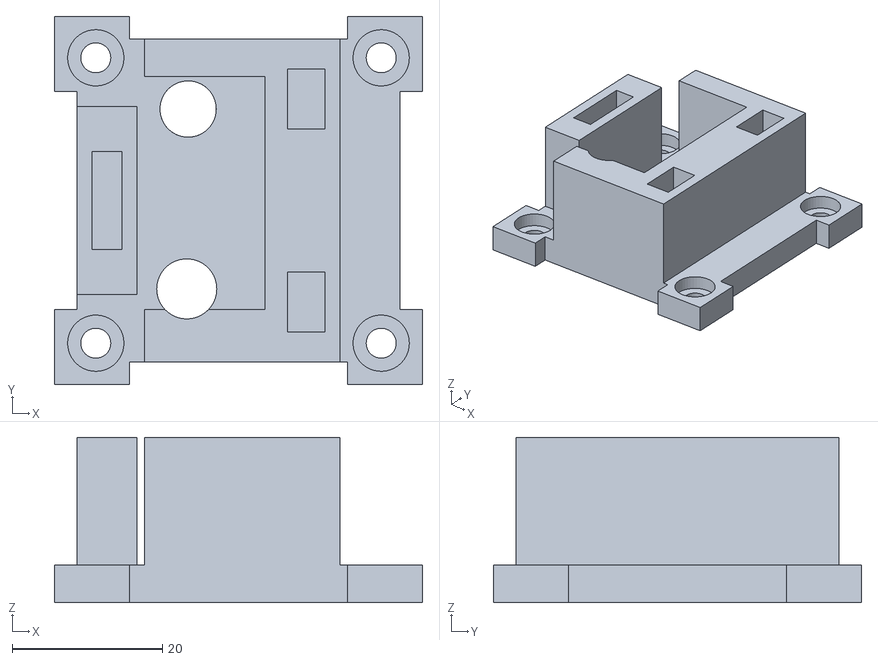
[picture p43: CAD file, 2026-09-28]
Full_Base_V2.stl
49.0 x 49.0 x 22.0

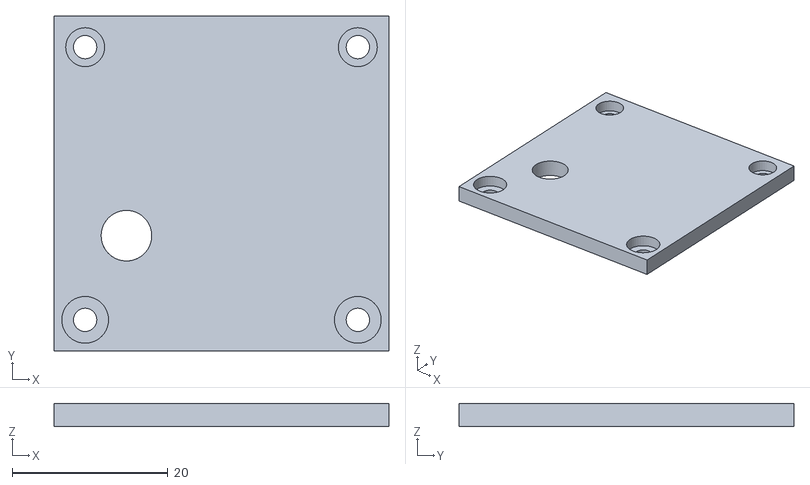
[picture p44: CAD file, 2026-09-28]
Base_v1.stl
43.0 x 43.0 x 3.00

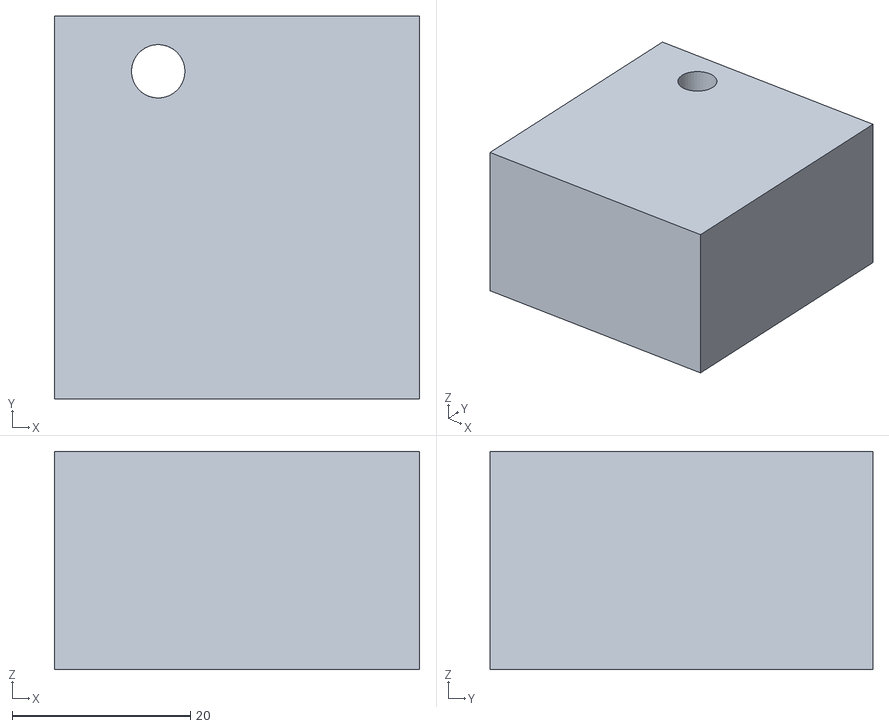
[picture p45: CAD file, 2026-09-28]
Prototype_number_1.stl
41.0 x 43.0 x 24.5

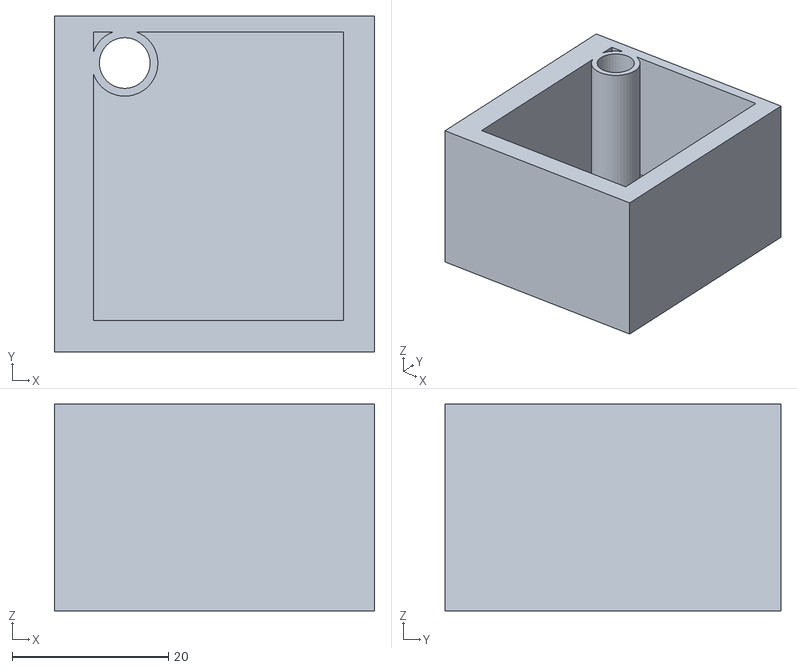
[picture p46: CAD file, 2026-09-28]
Prototype_number_2.stl
41.0 x 43.0 x 26.5

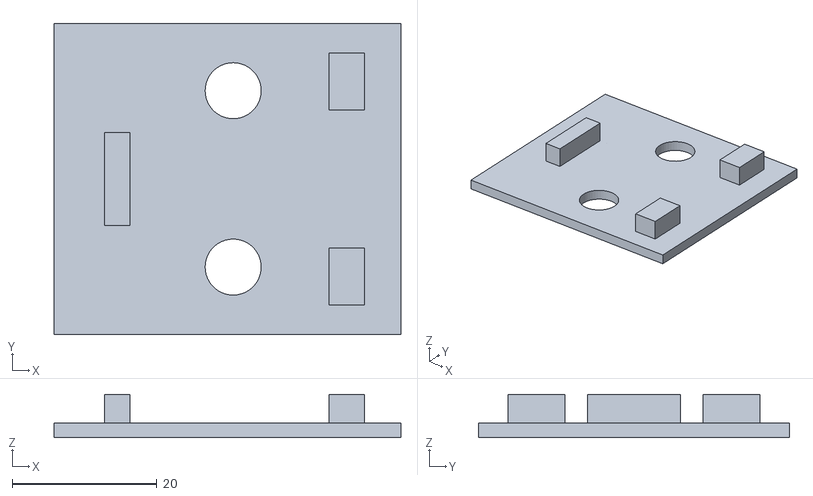
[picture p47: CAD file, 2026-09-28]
Top_V2.stl
48.0 x 43.0 x 6.00

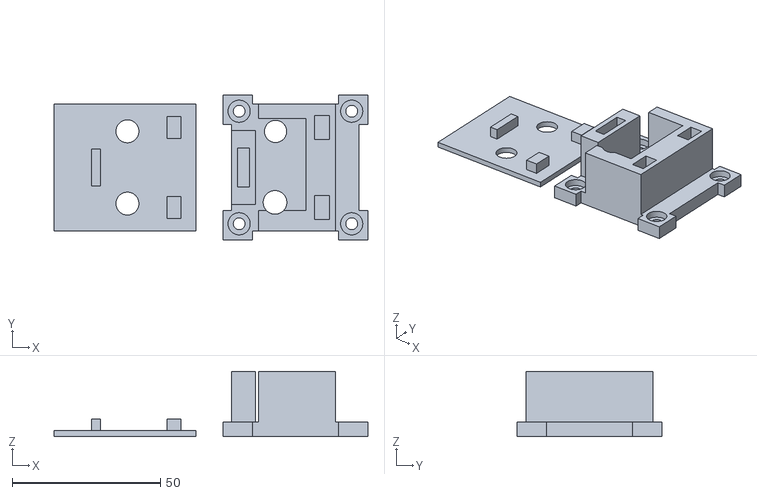
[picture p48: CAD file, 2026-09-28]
Final_Design.stl
106.0 x 49.0 x 22.0

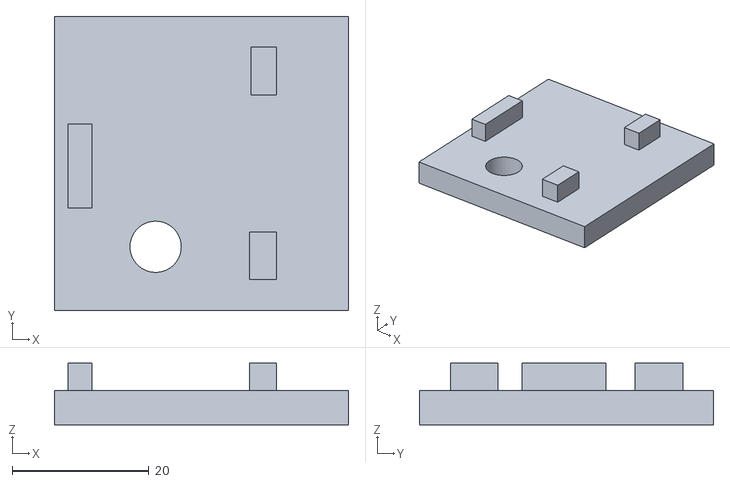
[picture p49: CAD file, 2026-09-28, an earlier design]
Top_V1.stl
43.0 x 43.0 x 9.00

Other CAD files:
Full_Base_V1.stl

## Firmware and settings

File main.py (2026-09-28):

import os
import json
import time
import logging
import asyncio
from typing import Optional, List, Dict, Any
from fastapi import FastAPI, HTTPException, Query, Request, File, UploadFile
from fastapi.staticfiles import StaticFiles
from fastapi.responses import StreamingResponse
from pydantic import BaseModel
import cv2
import numpy as np

from motor_controller import MotorController
from camera_controller import CameraController

logging.basicConfig(level=logging.INFO)
logger = logging.getLogger("main_app")

app = FastAPI(title="Quantum Optics Lab Controller")

MOTOR1_SERIAL = "27270997"
MOTOR2_SERIAL = "27271282"

motor1: Optional[MotorController] = None
motor2: Optional[MotorController] = None
camera: Optional[CameraController] = None

# Permanent optical calibration values (microns per pixel)
calibration_data = {
    "1x": 1.1152,
    "2x": 0.5984,
    "3x": 0.3973,
    "4x": 0.28655
}

# ==========================================
# --- Persistent Sequence Storage Logic  ---
# ==========================================
SEQUENCES_FILE = "sequences.json"

if os.path.exists(SEQUENCES_FILE):
    try:
        with open(SEQUENCES_FILE, "r") as f:
            saved_sequences: Dict[str, List[Dict[str, Any]]] = json.load(f)
        logger.info(f"Loaded {len(saved_sequences)} saved sequences from disk.")
    except Exception as e:
        logger.error(f"Failed to read {SEQUENCES_FILE}: {e}")
        saved_sequences: Dict[str, List[Dict[str, Any]]] = {}
else:
    saved_sequences: Dict[str, List[Dict[str, Any]]] = {}

def save_sequences_to_disk():
    try:
        with open(SEQUENCES_FILE, "w") as f:
            json.dump(saved_sequences, f, indent=4)
    except Exception as e:
        logger.error(f"Failed to save sequences to {SEQUENCES_FILE}: {e}")

class SequenceStep(BaseModel):
    position: Optional[float] = None
    pos: Optional[float] = None
    velocity: Optional[float] = None
    acceleration: Optional[float] = None
    pause_after: Optional[float] = 0.0
    pause: Optional[float] = 0.0

class SequencePayload(BaseModel):
    steps: List[SequenceStep]
    name: Optional[str] = None

class DualSequencePayload(BaseModel):
    motor1_steps: List[SequenceStep] = []
    motor2_steps: List[SequenceStep] = []
    motor1_name: Optional[str] = None
    motor2_name: Optional[str] = None

class VelocityPayload(BaseModel):
    velocity: float
    acceleration: float

class SavedSequence(BaseModel):
    name: str
    steps: List[SequenceStep]

def get_motor(motor_id: str) -> MotorController:
    if motor_id == "motor1":
        m = motor1
    elif motor_id == "motor2":
        m = motor2
    else:
        raise HTTPException(status_code=400, detail="Invalid motor ID")

    if m is None:
        raise HTTPException(status_code=500, detail=f"{motor_id} driver not initialized.")
    return m

@app.on_event("startup")
async def startup_hardware_init():
    global motor1, motor2, camera
    logger.info("Initializing Thorlabs Motor Controllers...")
    motor1 = MotorController(serial_number=MOTOR1_SERIAL, use_real_hardware=True)
    motor2 = MotorController(serial_number=MOTOR2_SERIAL, use_real_hardware=True)
    
    logger.info("Initializing Camera Controller...")
    camera = CameraController(use_real_hardware=True)

@app.on_event("shutdown")
async def shutdown_hardware():
    logger.info("Closing motor connections...")
    if motor1:
        motor1.close()
    if motor2:
        motor2.close()

# ==========================================
# --- Camera & Optics Calibration Routes ---
# ==========================================
def frame_generator():
    while True:
        if camera:
            frame = camera.get_frame_jpeg()
            if frame:
                yield (b'--frame\r\n'
                       b'Content-Type: image/jpeg\r\n\r\n' + frame + b'\r\n')

@app.get("/video_feed")
async def video_feed():
    return StreamingResponse(
        frame_generator(), 
        media_type="multipart/x-mixed-replace; boundary=frame"
    )

@app.get("/calibration")
async def get_calibration():
    return calibration_data

@app.post("/calibration")
async def save_calibration(request: Request):
    data = await request.json()
    zoom = data.get("zoom")
    microns_per_pixel = data.get("microns_per_pixel")
    if zoom and microns_per_pixel:
        calibration_data[zoom] = microns_per_pixel
    return calibration_data

@app.post("/camera/settings")
async def update_camera_settings(request: Request):
    if not camera:
        raise HTTPException(status_code=500, detail="Camera not initialized")
    
    data = await request.json()
    if "exposure" in data:
        camera.set_exposure(data["exposure"])
    if "gain" in data:
        camera.set_gain(data["gain"])
    if "width" in data and "height" in data:
        camera.set_resolution(data["width"], data["height"])
        
    return camera.get_resolution()

@app.post("/camera/auto_scale")
async def api_camera_auto_scale():
    if not camera:
        return {"status": "error", "message": "Camera not initialized"}
    result = camera.auto_scale(target_brightness=120.0)
    return result

@app.post("/camera/capture")
async def capture_image():
    if not camera:
        return {"error": "Camera not initialized"}
    
    frame_bytes = camera.get_frame_jpeg()
    if not frame_bytes:
        return {"error": "Failed to grab frame from camera"}
        
    os.makedirs(os.path.join("static", "captures"), exist_ok=True)
    
    filename = f"capture_{int(time.time())}.jpg"
    filepath = os.path.join("static", "captures", filename)
    
    with open(filepath, "wb") as f:
        f.write(frame_bytes)
        
    return {"filename": filename}

@app.get("/captures/list")
async def list_captures():
    captures_dir = os.path.join("static", "captures")
    captures = []
    if os.path.exists(captures_dir):
        for filename in sorted(os.listdir(captures_dir), reverse=True):
            if filename.endswith(".jpg"):
                captures.append({
                    "filename": filename,
                    "url": f"/captures/{filename}"
                })
    return captures

@app.post("/camera/measure_fiber")
async def measure_fiber():
    """Automatically measures fiber thickness by analyzing vertical gradients in the image."""
    if not camera:
        return {"error": "Camera not initialized"}
    
    frame_bytes = camera.get_frame_jpeg()
    if not frame_bytes:
        return {"error": "Failed to grab frame"}

    np_arr = np.frombuffer(frame_bytes, np.uint8)
    img = cv2.imdecode(np_arr, cv2.IMREAD_GRAYSCALE)

    if img is None:
        return {"error": "Failed to decode image"}

    # Isolate the center vertical slice to minimize noise from the edges
    h, w = img.shape
    center_x = w // 2
    roi = img[:, center_x-20:center_x+20]

    # Average the slice horizontally to create a clean 1D intensity profile
    profile = np.mean(roi, axis=1)

    # Calculate the gradient (1st derivative) to find sharp contrast edges
    gradient = np.abs(np.gradient(profile))

    # The fiber cladding boundaries represent the highest gradients (dark -> bright and bright -> dark)
    # Threshold at 30% of the maximum gradient peak to filter noise
    threshold = np.max(gradient) * 0.3
    edge_peaks = np.where(gradient > threshold)[0]

    if len(edge_peaks) < 2:
        return {"error": "Could not clearly detect outer fiber edges."}

    top_edge = edge_peaks[0]
    bottom_edge = edge_peaks[-1]
    pixel_width = float(bottom_edge - top_edge)

    return {"pixel_width": pixel_width}

# ==========================================
# --- Saved Sequences Routes ---
# ==========================================
@app.get("/sequences")
async def get_saved_sequences():
    return saved_sequences

@app.post("/sequences")
async def save_new_sequence(payload: SavedSequence):
    formatted_steps = []
    for s in payload.steps:
        formatted_steps.append({
            "position": s.position if s.position is not None else s.pos,
            "velocity": s.velocity,
            "acceleration": s.acceleration,
            "pause_after": s.pause_after if s.pause_after else s.pause
        })
    saved_sequences[payload.name] = formatted_steps
    save_sequences_to_disk()
    return saved_sequences

@app.delete("/sequences/{name}")
async def delete_saved_sequence(name: str):
    if name in saved_sequences:
        del saved_sequences[name]
        save_sequences_to_disk()
    return saved_sequences

@app.post("/sequences/upload")
async def upload_sequence_text_file(file: UploadFile = File(...)):
    """Accepts a text or CSV file formatted as: position, velocity, acceleration, pause"""
    content = await file.read()
    text = content.decode('utf-8')
    steps = []
    
    for line in text.splitlines():
        parts = line.split(',')
        if not parts or not parts[0].strip():
            continue
        try:
            pos = float(parts[0].strip())
            vel = float(parts[1].strip()) if len(parts) > 1 and parts[1].strip() else None
            acc = float(parts[2].strip()) if len(parts) > 2 and parts[2].strip() else None
            pause = float(parts[3].strip()) if len(parts) > 3 and parts[3].strip() else 0.0
            steps.append({
                "pos": pos,
                "velocity": vel,
                "acceleration": acc,
                "pause": pause
            })
        except ValueError:
            continue  # Skip headers or badly formatted lines

    if not steps:
        return {"error": "No valid sequence steps found in the file."}

    name = file.filename.rsplit('.', 1)[0]
    saved_sequences[name] = steps
    save_sequences_to_disk()
    
    return {"message": f"Sequence '{name}' uploaded successfully", "name": name}

# ==========================================
# --- Explicit Motor 1 Routes ---
# ==========================================
@app.get("/motor1/status")
async def get_motor1_status():
    return get_motor("motor1").get_status()

@app.post("/motor1/set_zero")
async def set_motor1_zero():
    return get_motor("motor1").set_custom_home()

@app.post("/motor1/move")
async def move_motor1(position: float = Query(...)):
    m = get_motor("motor1")
    m.move_to(position, wait=False)
    return {"status": "moving", "target_position": position}

@app.post("/motor1/home")
async def home_motor1():
    return get_motor("motor1").home()

@app.post("/motor1/velocity")
async def set_motor1_velocity(payload: VelocityPayload):
    m = get_motor("motor1")
    m.set_velocity_profile(payload.velocity, payload.acceleration)
    return {"status": "velocity_updated"}

@app.post("/motor1/stop")
async def stop_motor1():
    return get_motor("motor1").stop()

@app.post("/motor1/pause")
async def pause_motor1():
    return get_motor("motor1").pause()

@app.post("/motor1/resume")
async def resume_motor1():
    return get_motor("motor1").resume()

@app.post("/motor1/sequence")
async def run_motor1_sequence(payload: SequencePayload):
    formatted_steps = []
    for s in payload.steps:
        formatted_steps.append({
            "pos": s.position if s.position is not None else s.pos,
            "pause": s.pause_after if s.pause_after else s.pause,
            "velocity": s.velocity,
            "acceleration": s.acceleration
        })
    return get_motor("motor1").run_sequence(formatted_steps)

# ==========================================
# --- Explicit Motor 2 Routes ---
# ==========================================
@app.get("/motor2/status")
async def get_motor2_status():
    return get_motor("motor2").get_status()

@app.post("/motor2/set_zero")
async def set_motor2_zero():
    return get_motor("motor2").set_custom_home()

@app.post("/motor2/move")
async def move_motor2(position: float = Query(...)):
    m = get_motor("motor2")
    m.move_to(position, wait=False)
    return {"status": "moving", "target_position": position}

@app.post("/motor2/home")
async def home_motor2():
    return get_motor("motor2").home()

@app.post("/motor2/velocity")
async def set_motor2_velocity(payload: VelocityPayload):
    m = get_motor("motor2")
    m.set_velocity_profile(payload.velocity, payload.acceleration)
    return {"status": "velocity_updated"}

@app.post("/motor2/stop")
async def stop_motor2():
    return get_motor("motor2").stop()

@app.post("/motor2/pause")
async def pause_motor2():
    return get_motor("motor2").pause()

@app.post("/motor2/resume")
async def resume_motor2():
    return get_motor("motor2").resume()

@app.post("/motor2/sequence")
async def run_motor2_sequence(payload: SequencePayload):
    formatted_steps = []
    for s in payload.steps:
        formatted_steps.append({
            "pos": s.position if s.position is not None else s.pos,
            "pause": s.pause_after if s.pause_after else s.pause,
            "velocity": s.velocity,
            "acceleration": s.acceleration
        })
    return get_motor("motor2").run_sequence(formatted_steps)

# ==========================================
# --- Multi-Motor Sequence Route ---
# ==========================================
@app.post("/sequence/run_both")
async def run_both_sequences(payload: DualSequencePayload):
    def _run_synchronized_threads():
        m1 = get_motor("motor1")
        m2 = get_motor("motor2")
        
        steps1 = [{
            "pos": s.position if s.position is not None else s.pos, 
            "pause": s.pause_after if s.pause_after else s.pause,
            "velocity": s.velocity,
            "acceleration": s.acceleration
        } for s in payload.motor1_steps]
        
        steps2 = [{
            "pos": s.position if s.position is not None else s.pos, 
            "pause": s.pause_after if s.pause_after else s.pause,
            "velocity": s.velocity,
            "acceleration": s.acceleration
        } for s in payload.motor2_steps]
        
        res1 = m1.run_sequence(steps1) if steps1 else {"status": "no_steps"}
        res2 = m2.run_sequence(steps2) if steps2 else {"status": "no_steps"}
        return res1, res2

    loop = asyncio.get_running_loop()
    await loop.run_in_executor(None, _run_synchronized_threads)
    
    return {"status": "both_sequences_started"}

app.mount("/", StaticFiles(directory="static", html=True), name="static")

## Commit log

2026-09-28 Correct table formatting in README.md
    Fixed formatting issues in the README for the base plate section.
2026-09-28 Revise README structure and content
    Updated README to enhance project structure and clarity, including new sections for optical fiber heating enclosure and integrated lab control system.
2026-09-28 Revise README section titles and CAD file details
    Updated section titles and improved CAD file descriptions in README.
2026-09-28 Revise README for Quantum Optics Lab Stage Mounts
    Updated project title and description for Quantum Optics Lab stage mounts. Enhanced sections on design logic, prototyping approach, and added links to 3D printable models.
2026-10-30 Refactor CameraController for improved functionality
2026-10-30 Refactor motor controller for improved structure
